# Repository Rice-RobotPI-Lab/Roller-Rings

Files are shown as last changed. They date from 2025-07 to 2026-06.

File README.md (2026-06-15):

# Roller Ring - Modular, Wearable In-hand Manipulator
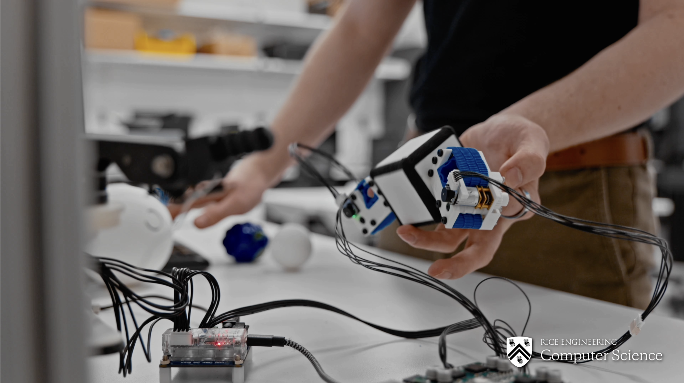
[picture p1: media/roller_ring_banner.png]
Roller Ring Image


This repository covers the CAD files, software, and instructions needed to operate the <ins>**Roller Ring**</ins>. The Roller Ring is a low-cost modular robotic attachment with active surfaces, that is wearable by both robot and human hands, to manipulate objects without lifting a finger. To create these movements, we developed and implemented a generalized motion model for active surfaces to manipulate arbitrary object shapes through non-holonomic object motions. To see further discussion of this device's physical capabilities and ideas behind it, please see the associated [research paper](https://arxiv.org/abs/2403.13132) which has been published in the [2025 IEEE/RSJ International Conference on Intelligent Robots and Systems (IROS 2025)](https://www.iros25.org) and won 3rd Place at the [ASME Student Mechanism and Robot Design Competition](https://sites.google.com/site/asmemrc/design-competition-showcase/2024-finalists?authuser=0). For device licensing, commerical use, or future collaboration of the Roller Ring, please contact [<ins>**Hayden Webb**</ins>](hw846@cornell.edu) and/or [<ins>**Kaiyu Hang**</ins>](kaiyu.hang@rice.edu). <br>

<p align="center">
  <a href="https://youtu.be/WcgoPhGvVFQ?si=lwNhkjuWtoK7LcqY">
    
  </a>
</p>

<p align="center">
    <u><b>Promotional Video</b></u>
</p>
<br>
Roller Ring Motion Example

<p align="center">
    <u><b>Manipulation Capabilities</b></u>
</p>

## Hardware
In **hardware** you'll find the STL files for printing the Roller Rings using an FDM Printer (Bambu, Prusa, etc.). Full Bill of Materials for non 3D-printed components can be found in the Bill of Materials under **BOM_mechanical.xlsx**. Video instruction for mechanical construction can be found below. <br>

<p align="center">
  <a href="https://www.youtube.com/watch?v=R2PSydqvgRo">
    
  </a>
</p>
<p align="center">
    <u><b>Construction Video</b></u>
</p>

## Software
In **software**, you'll find the teleoperation script for controlling the Roller Rings. In this, options for using either a keyboard or game controller for teleoperation is provided. For full documentation and origin of Teensy motor script & board utilized in teleoperation, please refer to the README found in this folder. The board and motor-related components can be found in the Bill of Materials under **BOM_electrical.xlsx** . <br>

For further questions and inquiries regarding the software and PCB detailed here, please contact [Shenli Yuan](https://yuanshenli.com/). <br>

## Citation
If this project has helped you in your projects, you can cite this work with:

```bibtex
@inproceedings{2403.13132,
    Author = {Hayden Webb and Podshara Chanrungmaneekul and Shenli Yuan and Kaiyu Hang},
    booktitle = {2025 IEEE/RSJ International Conference on Intelligent Robots and Systems (IROS)},
    Title = {Wearable Roller Rings to Augment In-Hand Manipulation through Active Surfaces},
    Year = {2025},
    Volume = {},
    Number = {},
    Pages = {},
    keywords = {In-Hand Manipulation; Multifingered Hands},
    doi = {},
    Eprint = {arXiv:2403.13132}
}
```

## Patent
Further information detailing this work's patent information titled "Wearable roller rings to enable robot dexterous in-hand manipulation through active surfaces" can be found [here](https://patents.google.com/patent/US20260008186A1/en) from the USPTO.

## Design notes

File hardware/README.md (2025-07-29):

Roller Ring Hardware
=============================================

### Description

- Components, outside of the belt and CASM, were toleranced and printed around using PLA ([Bambu PLA Basic](https://us.store.bambulab.com/products/pla-basic-filament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)) on a Bambu X1C. The belt and CASM were toleranced and printed around using TPU ([NinjaTek Chinchilla 75A](https://ninjatek.com/shop/chinchilla/)) on a Bambu A1.
- Other filaments can be utilized as long as the material properties are comparable to the aforementioned filaments 
- In the event of using different printers, some light sanding may be required to ensure component can be installed.

For further questions and inquiries regarding the hardware detailed here, please contact [Hayden Webb](https://webbhayden.com/).

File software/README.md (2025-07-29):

Roller Ring Software
=============================================

### Description

- Low level control, and python API used for the project are provided in [rgSerial](https://github.com/yuanshenli/rgSerial/tree/rgserial_4motor). This is the same codebase used in both the [Tactile-Reactive Roller Grasper](https://yuanshenli.com/tactile_reactive_roller_grasper.html) and the [Belt–Augmented Compliant Hand](https://yuanshenli.com/bach.html). 
- The gerber file for the PCB can be found in [Tactile-Reactive-Roller-Grasper repository](https://github.com/yuanshenli/Tactile-Reactive-Roller-Grasper) <br>
- For controller and keyboard use, you'll need to install pygame>=2.1.0 to interface with the motors

For further questions and inquiries regarding the hardware detailed here, please contact [Shenli Yuan](https://yuanshenli.com/).

```python
pip install pygame
```

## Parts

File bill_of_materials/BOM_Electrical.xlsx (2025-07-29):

Name | Price | Quantity | Description
Cap Pol2 (https://octopart.com/eeu-fc1h100l-panasonic-39478539) | $0.08 | 1 | Cap Aluminum Lytic 10uF 50V 20%( 5 X 11mm) Radial 5mm 250mA 5000h 105C Ammo
Pololu POLOLU-1213 (https://octopart.com/mc33926pnbr2-nxp+semiconductors-70299439) | $2.00 | 2 | DC-motor driver; IC: MC33926; 20kHz; 2.5A; Uin mot: 5÷28V
JST B6B-ZR (https://octopart.com/b6b-zr+%28lf%29%28sn%29-jst-23254640) | $0.24 | 4
JST B3B-EH-A(LF)(SN) (https://octopart.com/s3b-eh%28lf%29%28sn%29-jst-248790) | $0.08 | 1 | Connector Header, EH Series, 3 Position, 2.5mm, Through Hole, Press-Fit, Solder, Natural
SparkFun DEV-16771 (https://octopart.com/4622-adafruit+industries-109144911) | $41.83 | 1 | Teensy 4.1 Development Board
Tracopower TSR 1-2450 (https://www.digikey.com/en/products/detail/traco-power/TSR-1-2450/9383780) | $6.16 | 1 | TRACOPOWER Switching Regulator; 6.5 - 36V dc Input; 5V Output; 1A
PCB | $25.00 | 1 | Cost estimate for 5 of PCB from PCBWay
Total | $78.11

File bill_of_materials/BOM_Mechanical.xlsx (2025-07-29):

Name | Price | Unit Quantity | Description | $/Min.Quantity
M2_25 Screw (https://www.mcmaster.com/92981A775/) | $5.08 | 3 | 3 mm Shoulder Diameter, 25 mm Shoulder Length, M2 x 0.4 mm Thread | 15.24
M2_30 Screw (https://www.mcmaster.com/92981A776/) | $5.33 | 4 | 3 mm Shoulder Diameter, 30 mm Shoulder Length, M2 x 0.4 mm Thread | 21.32
Bearing (https://www.amazon.com/MF63ZZ-Miniature-Bearings-Shielded-Pre-Lubricated/dp/B0CRLGCZJN) | $8.99 | 1 | Flanged Ball Bearing, ID 3mm x OD 6mm x Width 2.5mm Miniature Bearing | 0.899
Nylon Spacer (https://www.mcmaster.com/93657A203/) | $1.24 | 18 | Nylon Unthreaded Spacer, 4.5 mm OD, Off-White, 3 mm Long, for M3 Screw Size | 22.32
Roller Bearing (https://www.amazon.com/uxcell-HK0306-Needle-Roller-Bearings/dp/B07GC8NC5R) | $6.99 | 12 | HK0306 Drawn Cup Needle Roller Bearings, Open End, 3mm Bore Dia, 6.5mm OD, 6mm Width | 16.78
Locknut (https://www.mcmaster.com/90576A211/) | $18.00 | 7 | Medium-Strength Steel Nylon-Insert Locknut, Class 8, Zinc-Plated, M2 x 0.4 mm Thread Size | 18
N20 Motor (https://www.amazon.com/Encoder-Torque-7-5-3000RPM-Geared-Sensor/dp/B0DB26H17D) | $23.99 | 1 | DC 12V 80RPM N20 Encoder Motor | 11.99
PLA (https://us.store.bambulab.com/products/pla-basic-filament) | $19.99 | 1 | Bambu PLA Basic - White | 0.3998
TPU (75A) (https://ninjatek.com/shop/chinchilla/) | $64.49 | 1 | Chinchilla 3D Printer Filament (75A) | 1.03184
Total | $107.98

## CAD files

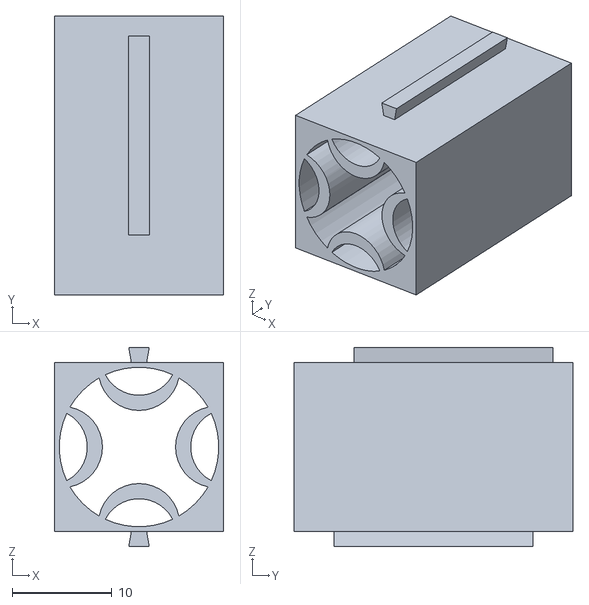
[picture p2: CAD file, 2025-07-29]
hardware/[Roller Ring] CASM.STL
17.0 x 28.0 x 20.0

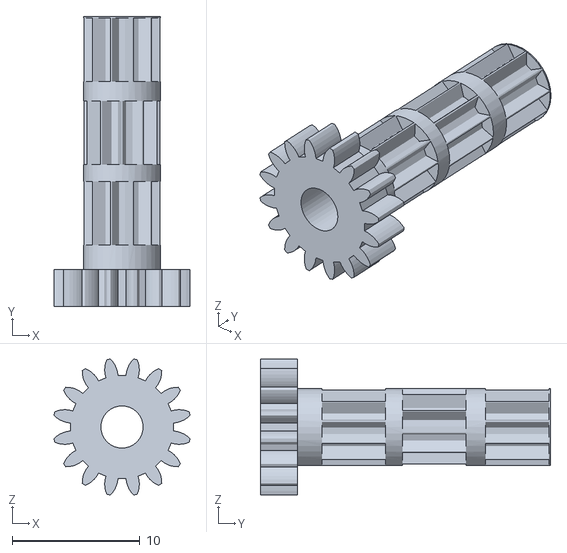
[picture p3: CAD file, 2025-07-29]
hardware/[Roller Ring] Roller Spur.STL
10.6 x 22.7 x 10.6

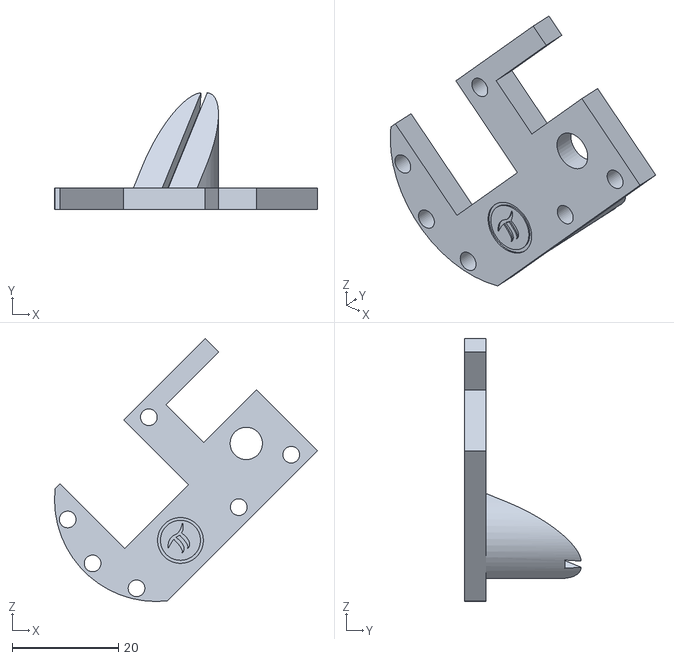
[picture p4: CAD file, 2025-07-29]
hardware/[Roller Ring] Top Plate.STL
49.6 x 22.0 x 49.6

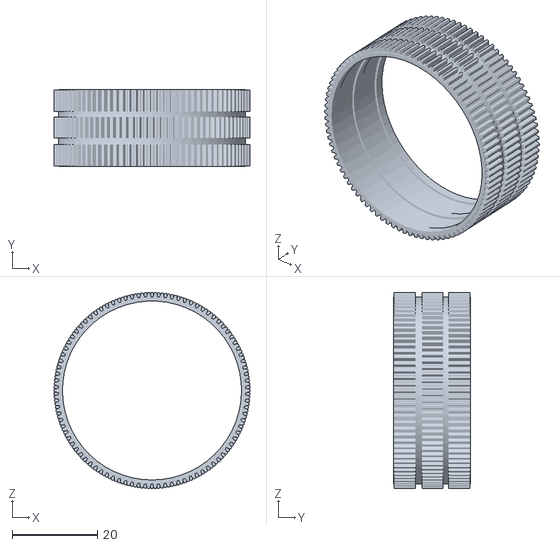
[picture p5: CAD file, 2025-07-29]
hardware/[Roller Ring] Belt.STL
46.0 x 18.0 x 46.0

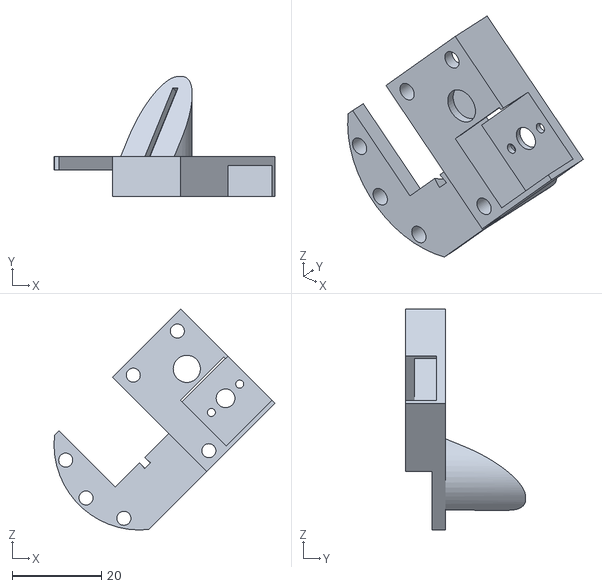
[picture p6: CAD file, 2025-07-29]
hardware/[Roller Ring] Bottom Plate.STL
49.6 x 27.0 x 49.6

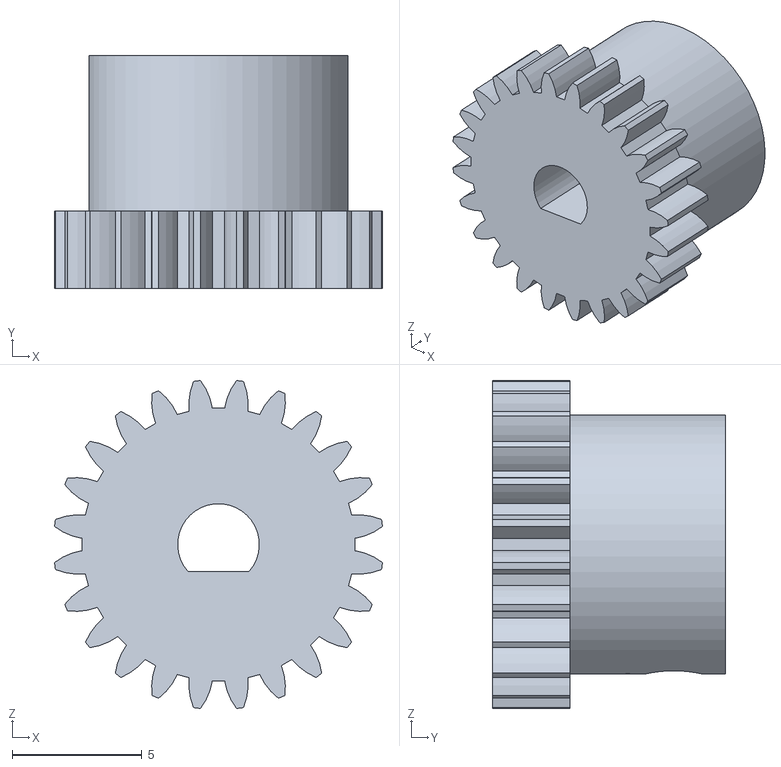
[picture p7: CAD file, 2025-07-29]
hardware/[Roller Ring] N20 Motor Gear.STL
12.7 x 9.00 x 12.7
